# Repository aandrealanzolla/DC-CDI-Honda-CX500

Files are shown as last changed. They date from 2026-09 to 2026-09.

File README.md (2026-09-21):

# CX500 CDI — Custom ignition control unit

STM32-based custom DC-CDI for a Honda CX500, V-twin wasted-spark with variable reluctance pickups. Ignition timing with variable, custom advance curve and reactive/predictive logic.

## Project status

- **Rev 1.3** — Selected MCU: STM32F411CEU6. Wrong SMPS transformer dimensioning. Wrong pickup input signal conditioning circuit.
- **Rev 1.3.1** — Added a daughter board with MAX9927 IC for VR pickup reading. Replaced old step-up transformers with DA2034. Almost fully working and road-tested.
- **Rev 2.0** — SUPERSEDED. Improved routing, transformer footprint update, added JAE 18-pin automotive connector.
- **Rev 2.1** — SUPERSEDED. SMPS controller change: from LT3758 (Analog Devices) to LM3481 (TI). Transformer change: from Coilcraft DA2034 to Würth 750032052.
- **Rev 2.2** — IN PRODUCTION. Migration to STM32F410CBU6 for PCBA cost reduction (pin remapping required). SMPS voltage increased from 290V to 400V. CDI capacitance decreased from 2.2uF to 1.5uF. 

⚠️ **Use**: hobby project, intended for vintage or racing motorcycles. No EMC or road-use certification. See `docs/` for the regulatory considerations evaluated.

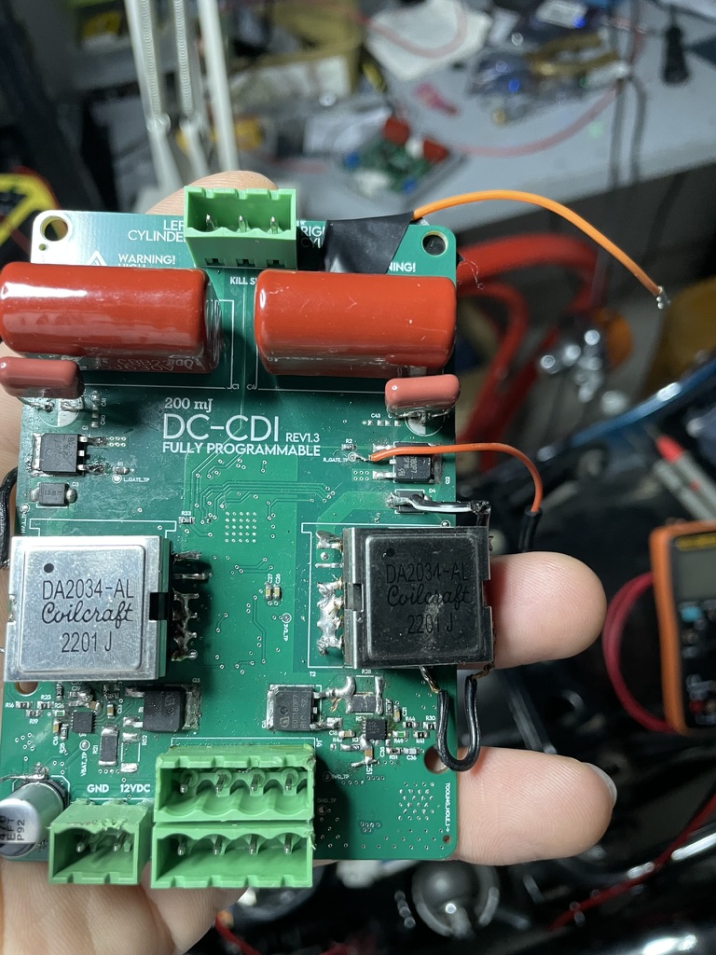
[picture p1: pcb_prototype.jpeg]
rev1.3 pcb assembled

rev1.3 pcb mounted
## Hardware architecture

### Rev 1.x (STM32F411CEU6)

| | Left channel | Right channel |
|---|---|---|
| Pickup capture | TIM3 CH3 | TIM2 CH3 |
| Spark coil output | TIM2 CH1 | TIM1 CH1 |

### Rev 2.x (STM32F410CBU6)

STM32F410 lacks TIM2/TIM3/TIM4 (value-line part), timers remapped as follows. TIM1 now
carries both right-channel output and left-channel capture on independent channels of the
same instance (shared prescaler/tick rate); TIM5 (32-bit) takes over TIM2's former dual role
(left output + right capture).

| | Left channel | Right channel |
|---|---|---|
| Pickup capture | TIM1 CH4 | TIM5 CH3 |
| Spark coil output | TIM5 CH1 | TIM1 CH1 |

Turned to Texas Instrument LM3481 SMPS controllers, to reduce complexity and costs. Increased capacitor charging voltage to 400V while reducing capacitance to 1.5uF to gain spark power (from 90mJ to 120mJ). 
Replaced ADP3654 with two 1EDN7511B.
Added external connector: JAE MX23A18 (waterproof) with UART access for engine map download/upload.

### Common to all revisions

- Pickup: MAX9927 (variable reluctance comparator), fixed angle 15° BTDC
- Power stage: IPD60R180P7 MOSFET (DPAK)
- External pins for kill switch, I2C sensors and analog sensor read with 5VDC power supply. 
- FW/Debug connector: STDC14 header (debug + calibration from the same node)

## Firmware architecture

- 4-branch state machine per channel: **reactive** (below 1500rpm, fixed 15° advance), **predictive-continuous**, **transition** (first threshold crossing), **drop-out**
- RPM projection: pure linear extrapolation, activation threshold `RPM_PROJECTION_MIN_RATE_PCT`
- Anti-stuck safety net: `PENDING_STUCK_TIMEOUT_MS`
- Advance map calibration: dedicated flash sector (last available sector), loaded at boot with fallback to safe defaults, writable over UART without reflashing (see `tools/cdi_calibration_tool.py`)
- UART telemetry at 115200 baud: rpm, advance, active branch, diagnostic counters (arm count, rejects, transitions, stuck-recovered)

## Repository structure

```
Progetto/
  DC_CDI_Honda_CX500_rev1.3/         - Altium project, rev 1.3 (working - with some rework, road-tested)
  DC_CDI_Honda_CX500_rev2.0/         - Altium project, rev 2.0 (SUPERSEDED)
  DC_CDI_Honda_CX500_rev2.1/         - Altium project, rev 2.1 (SUPERSEDED)
  DC_CDI_Honda_CX500_rev2.2/         - Altium project, rev 2.2 (IN PRODUCTION)
  DC_CDI_Honda_CX500_daughter_board_1/ - MAX9927 pickup daughter board
  Housing/
    rev1.3/                          - STEP/STL/OBJ enclosure models
    rev2.0/
  Documentazione/                    - PDFs
  simulazioni_LTspice/               - LTSpice simulation files
  firmware/                          - firmware version notes
  oldes_versions/                    - pre-rev1.3 Altium history
  smps_dimensionamento.xlsx
  stm32f411xx_RegisterMap.pdf
Video-Foto/                          - photos/videos of the build
Log_fw/                              - firmware telemetry logs
Misure/                              - oscilloscope captures
Sim/                                 - misc simulation files

```

## Main milestones (timeline)

1. Diagnosed and fixed cranking resets (gate resistor 0Ω → 10Ω, EMI from excessive dV/dt)
2. Replaced power stage: SCR → MOSFET
3. Fixed logic bugs: unstable RPM projection, drop-out arming a duplicate shot, queue firing on an expired target
4. Tuned advance map (aligned to stock AC-CDI reference, 37° at 5800rpm)
5. Isolated coupled noise on the left channel (daughter board repositioning)
6. Recurring MOSFET failures on the left channel — investigation ongoing (suspects: gate solder joint, driver, undersized Rds(on) on replacement parts)
7. Flash-based calibration system + PC tool
8. Migration to STM32F410 for cost reduction (rev 2.2)

## License

_TBD_

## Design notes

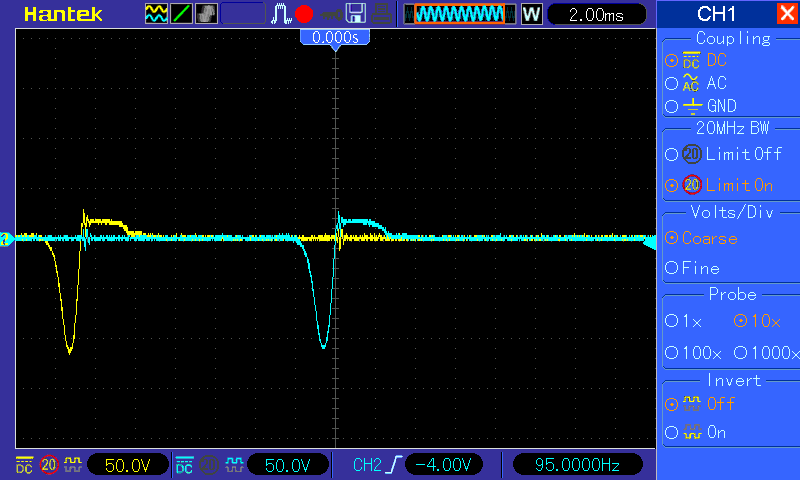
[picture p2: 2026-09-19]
Misure/pic_213_1.bmp

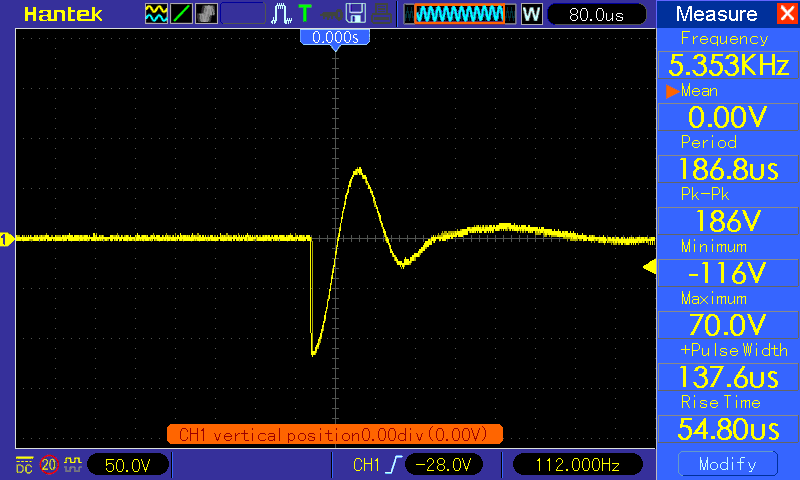
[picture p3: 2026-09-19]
Misure/pic_213_6.bmp

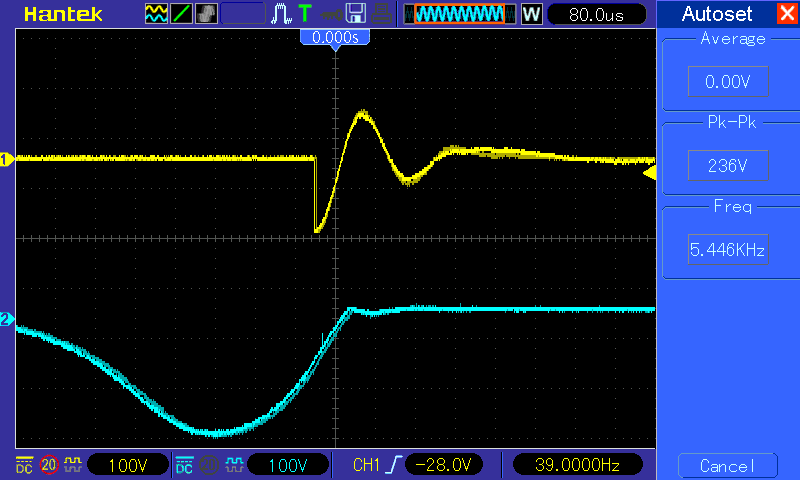
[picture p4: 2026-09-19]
Misure/pic_213_5.bmp

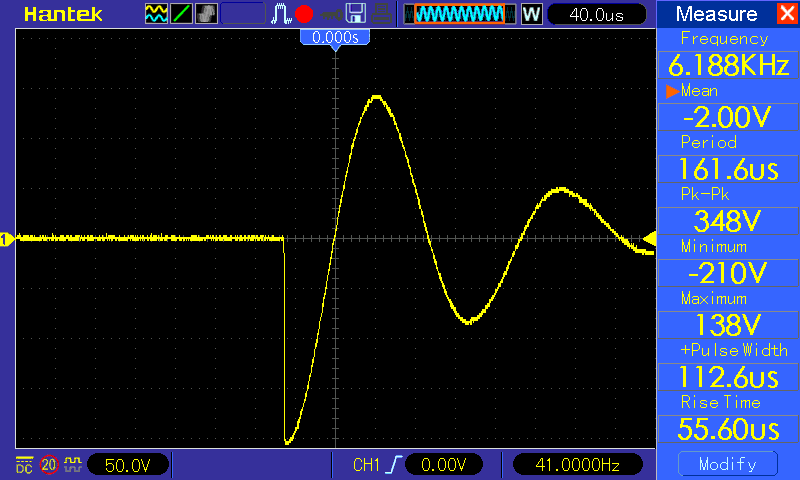
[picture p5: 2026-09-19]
Misure/pic_213_4.bmp

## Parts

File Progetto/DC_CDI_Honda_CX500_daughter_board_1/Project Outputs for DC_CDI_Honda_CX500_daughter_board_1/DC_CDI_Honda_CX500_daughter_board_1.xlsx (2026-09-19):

Name | Designator | Footprint | Value
Capacitor_0603 | C1 | 0603_FP | 47 nF
Capacitor_0603 | C2 | 0603_FP | 47 nF
Capacitor_0603 | C3 | 0603_FP | 100 nF
Resistor_0603 | R1 | 0603_FP | 10 kΩ
Resistor_0402 | R2 | 0402_fp | 10 kΩ
Resistor_0402 | R3 | 0402_fp | 100 Ω
Resistor_0402 | R4 | 0402_fp | 10 kΩ
Resistor_0603 | R5 | 0603_FP | 10 kΩ
Resistor_0402 | R6 | 0402_fp | 100 Ω
Resistor_0402 | R7 | 0402_fp | 100 Ω
MAX9926UAEE+ | U1 | FP-E16-1-MFG

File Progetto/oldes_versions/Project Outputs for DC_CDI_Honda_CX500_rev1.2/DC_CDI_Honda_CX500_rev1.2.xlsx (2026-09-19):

Comment | Designator | Footprint
GRM21BR61C475KA88L | C1 | CAPC2013X135X45LL10T25
BFC233820225 | C2 | FP-BFC233820225-MFG
B32672Z4105K000 | C3 | FP-B32672Z4105K000-MFG
C1608X5R1H105K080AB | C4 | FP-C1608-080-0_1-IPC_B
06035C104KAT4A | C5 | CAPC1608X90X35LL15T15
CC0603KRX7R9BB101 | C6 | FP-CC0603-DA-MFG
C0603C475K8PACTU | C7 | CAPC1608X87X35NL15T15
06035C103KAT2A | C8 | FP-0603-L_1_6_0_15-W_0_81-MFG
GRM21BR61C475KA88L | C9 | CAPC2013X135X45LL10T25
BFC233820225 | C10 | FP-BFC233820225-MFG
B32672Z4105K000 | C11 | FP-B32672Z4105K000-MFG
UUD1A102MNL1GS | C12 | NIC-CAPA2-10X10_V
C1608X5R1H105K080AB | C13 | FP-C1608-080-0_1-IPC_B
UUD1A102MNL1GS | C14 | NIC-CAPA2-10X10_V
CC0603KRX7R9BB101 | C15 | FP-CC0603-DA-MFG
06035C103KAT2A | C16 | FP-0603-L_1_6_0_15-W_0_81-MFG
GRM1555C1H102JA01D | C17 | FP-GRM155-0_05-IPC_B
GRM155R61A334KE15D | C18 | CAPC1005X55X25ML05T10
GRM155R61A334KE15D | C19 | CAPC1005X55X25ML05T10
GRM1555C1H331JA01D | C20 | FP-GRM155-0_05-MFG
GRM1555C1H102JA01D | C21 | FP-GRM155-0_05-IPC_B
GRM155R61A334KE15D | C22 | CAPC1005X55X25ML05T10
GRM155R61A334KE15D | C23 | CAPC1005X55X25ML05T10
GRM1555C1H331JA01D | C24 | FP-GRM155-0_05-MFG
CL05A106MP5NUNC | C25 | FP-CL05A106MP5NUNC-MFG
C0402C104K8PACTU | C26 | FP-C0402-BB-MFG
CL05A106MP5NUNC | C27 | FP-CL05A106MP5NUNC-MFG
C0402C104K8PACTU | C28 | FP-C0402-BB-MFG
CL05A106MP5NUNC | C29 | FP-CL05A106MP5NUNC-MFG
C0402C104K8PACTU | C30 | FP-C0402-BB-MFG
CL05A106MP5NUNC | C31 | FP-CL05A106MP5NUNC-MFG
C0402C104K8PACTU | C32 | FP-C0402-BB-MFG
GRM155R61A225KE95D | C33 | FP-GRM155-0_05-MFG
GRM155R61A225KE95D | C34 | FP-GRM155-0_05-MFG
C0402C104K8PACTU | C35 | FP-C0402-BB-MFG
C0402C104K8PACTU | C36 | FP-C0402-BB-MFG
C0402C104K8PACTU | C37 | FP-C0402-BB-MFG
C3D03060E | D1 | FP-TO-252-2_v2-MFG
C3D03060E | D2 | FP-TO-252-2_v2-MFG
150080SS75000 | D3 | WL-SMCW_0805_150080xx75000
150080SS75000 | D4 | WL-SMCW_0805_150080xx75000
FTSH-107-01-L-DV-K | J1 | FP-FTSH-107-01-L-DV-K-MFG
53047-0410 | J2 | FP-53047-0410-MFG
691701510002B | P1 | 691701510002B
691701510002B | P2 | 691701510002B
691701510002B | P3 | 691701510002B
691701510002B | P4 | 691701510002B
IPD600N25N3 | Q1 | INF-PG-TO252-3-11_A_L
IPD600N25N3 | Q2 | FP-PG-TO252-3-MFG
IPD600N25N3 | Q3 | INF-PG-TO252-3-11_A_L
IPD600N25N3 | Q4 | FP-PG-TO252-3-MFG
IPD600N25N3 | Q5 | INF-PG-TO252-3-11_A_L
PMV56XN,215 | Q6 | NXP-SOT23_L
CRCW060347R0FKEA | R1 | RESC1609X50X30LL10T20
RC0603FR-07470KL | R2 | RESC1608X55X25ML10T15
ERJ-3EKF1243V | R3 | RESC1608X55X30LL15T15
RC0603FR-0756KL | R4 | RESC1608X55X25LL10T15
RC0603FR-071KL | R5 | FP-RC0603-0_55-IPC_C
CRA2512-FZ-R020ELF | R6 | FP-CRA2512-MFG
RC0603FR-07470KL | R7 | RESC1608X55X25ML10T15
RC0603FR-07120KL | R8 | RESC1608X55X25NL10T15
RC0603FR-0710KL | R9 | FP-RC0603-0_55-IPC_C
ERJ-3EKF1243V | R10 | RESC1608X55X30LL15T15
RC0603FR-0756KL | R11 | RESC1608X55X25LL10T15
RC0603FR-071KL | R12 | FP-RC0603-0_55-IPC_C
CRCW060347R0FKEA | R13 | RESC1609X50X30LL10T20
RC0603FR-07120KL | R14 | RESC1608X55X25NL10T15
CRA2512-FZ-R020ELF | R15 | FP-CRA2512-MFG
RC0603FR-0710KL | R16 | FP-RC0603-0_55-IPC_C
RC0402FR-07560KL | R17 | RESC1005X40X25LL05T10
RC0402FR-0722KL | R18 | RESC1005X40X25NL05T10
RC0402FR-0722KL | R19 | RESC1005X40X25NL05T10
RC0402FR-0722KL | R20 | RESC1005X40X25NL05T10
RC0402FR-072M2L | R21 | RESC1005X40X25ML05T10
RC0402FR-071M5L | R22 | RESC1005X40X25NL05T10
RC0402FR-07560KL | R23 | RESC1005X40X25LL05T10
RC0402FR-0722KL | R24 | RESC1005X40X25NL05T10
RC0402FR-0722KL | R25 | RESC1005X40X25NL05T10
RC0402FR-0722KL | R26 | RESC1005X40X25NL05T10
RC0402FR-072M2L | R27 | RESC1005X40X25ML05T10
RC0402FR-071M5L | R28 | RESC1005X40X25NL05T10
RC0402FR-0710KL | R29 | RESC1005X40X25LL05T10
RC0402FR-0710KL | R30 | RESC1005X40X25LL05T10
RC0402FR-0710KL | R31 | RESC1005X40X25LL05T10
RC0402FR-07510RL | R32 | RESC1005X40X25LL05T10
RC0402FR-07510RL | R33 | RESC1005X40X25LL05T10
RC0402FR-0710KL | R34 | RESC1005X40X25LL05T10
RC0402JR-070RL | R35 | RESC1005X40X25NL05T10
RC0402JR-070RL | R36 | RESC1005X40X25NL05T10
RC0402FR-0710KL | R37 | RESC1005X40X25LL05T10
RC0402JR-074K7L | R38 | FP-RC0402-0_4-MFG
RC0402JR-074K7L | R39 | FP-RC0402-0_4-MFG
RC0603FR-07470KL | R50 | RESC1608X55X25ML10T15
RC0603FR-07470KL | R51 | RESC1608X55X25ML10T15
74080 | T1 | 74080
74080 | T2 | 74080
LT3758EDD#PBF | U1 | FP-DD-10-05-08-1699-IPC_B
ADP3654ARHZ-RL | U2 | FP-RH-8-1-IPC_C
LT3758EDD#PBF | U3 | FP-DD-10-05-08-1699-IPC_B
AD8602DRM-REEL | U4 | ADI-RM-8_M
AD8602DRM-REEL | U5 | ADI-RM-8_M
AMS1117-3.3 | U7 | FP-AMS1117-IPC_C
STM32H750VBT6 | U8 | FP-LQFP100-1L-MFG
AD8031ARTZ-REEL7 | U9 | ADI-RJ-5_L

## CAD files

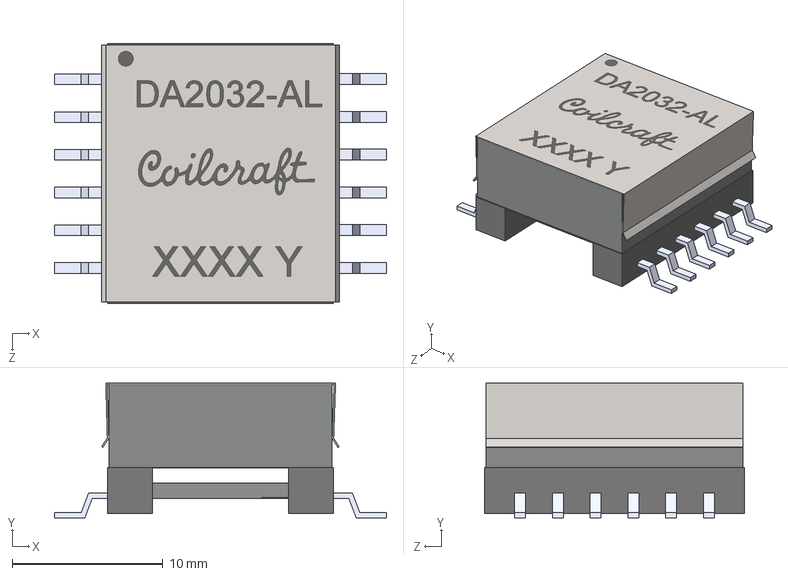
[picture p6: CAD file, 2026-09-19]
Progetto/DC_CDI_Honda_CX500_rev2.2/Coilcraft-DA2032-AL.STEP
22.0 x 8.94 x 17.2 mm

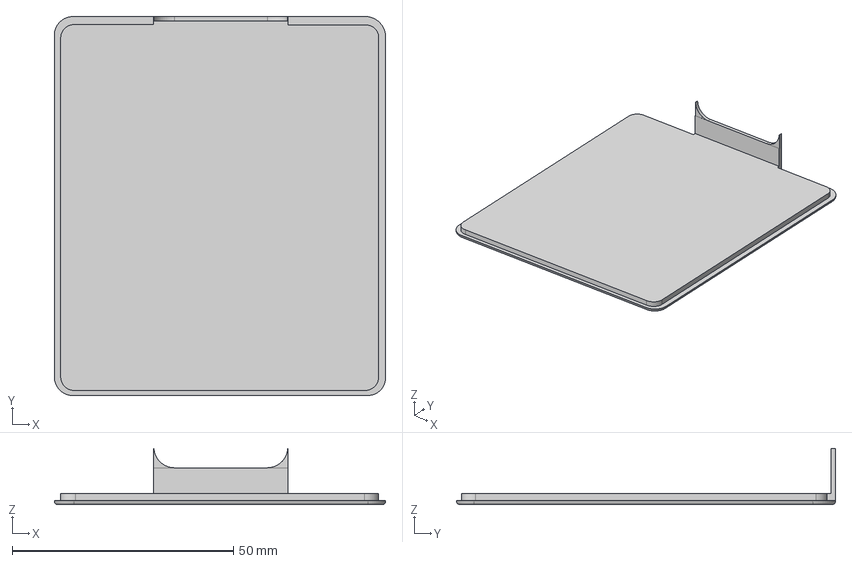
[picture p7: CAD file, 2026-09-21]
Progetto/Housing/rev2.2/housing_bot.step
74.9 x 85.7 x 12.7 mm

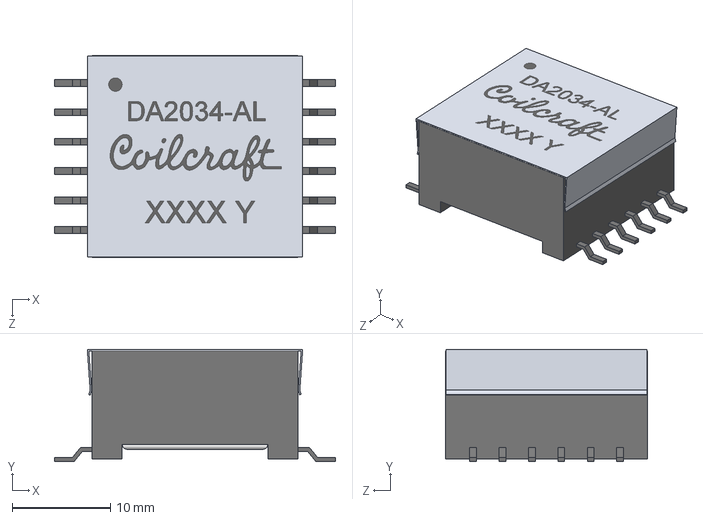
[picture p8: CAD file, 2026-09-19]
Progetto/DC_CDI_Honda_CX500_rev2.2/Coilcraft-DA2034-AL.STEP
28.6 x 11.4 x 20.6 mm

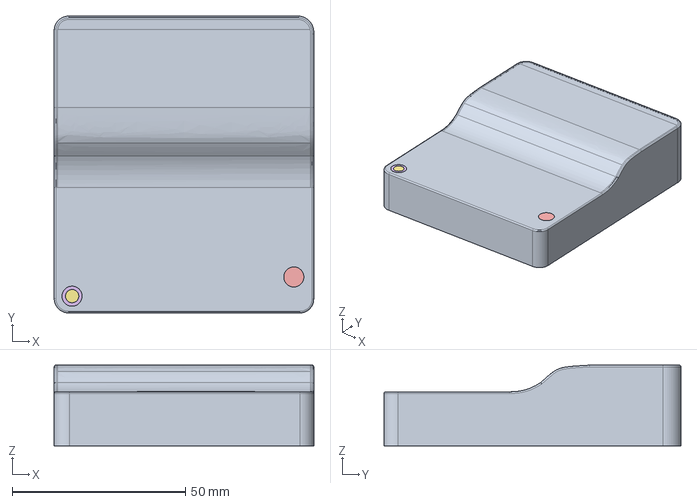
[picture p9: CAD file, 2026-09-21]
Progetto/Housing/rev2.2/housing_top.step
74.9 x 85.7 x 23.3 mm

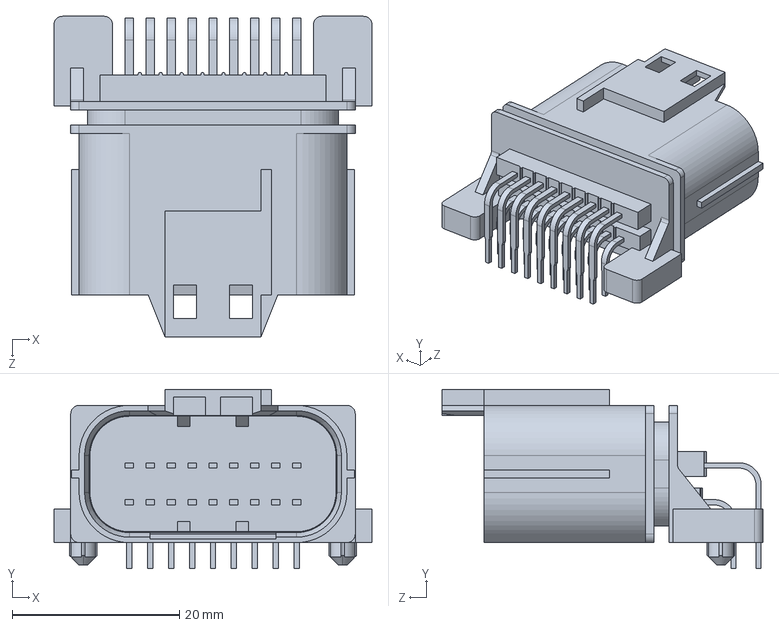
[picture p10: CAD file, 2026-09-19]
Progetto/DC_CDI_Honda_CX500_rev2.2/MX23A18NF1.stp
38.0 x 21.4 x 38.3 mm

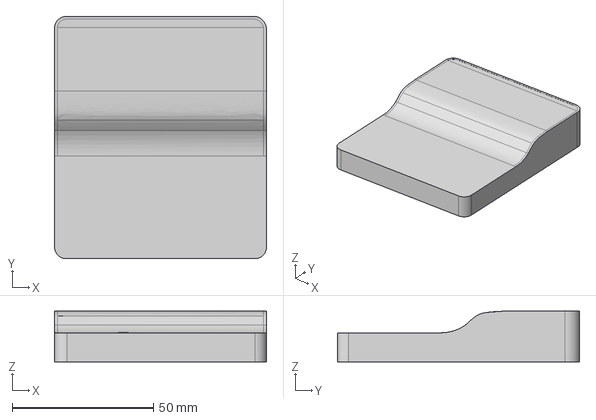
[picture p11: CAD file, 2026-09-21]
Progetto/Housing/rev2.2/housing.step
74.9 x 85.7 x 18.0 mm

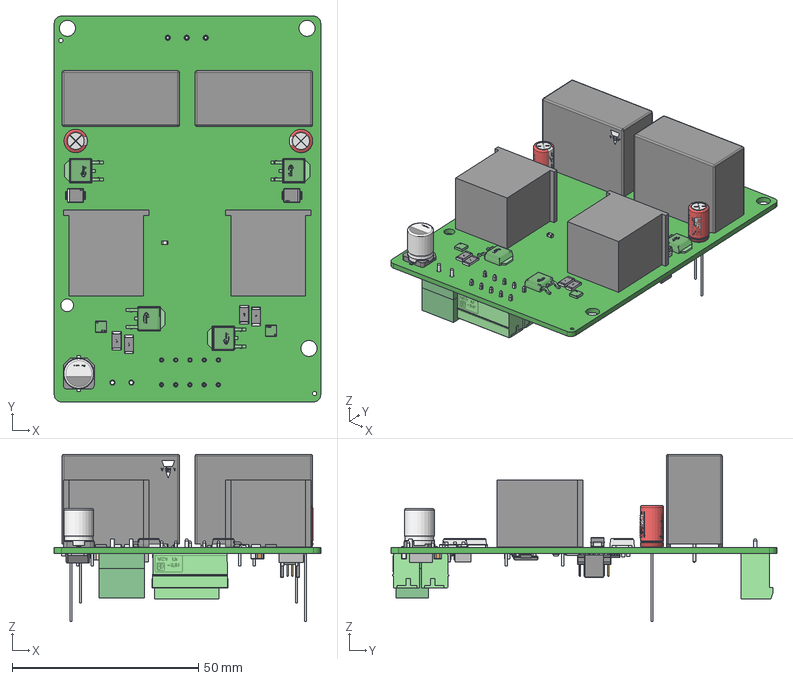
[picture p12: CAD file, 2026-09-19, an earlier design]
Progetto/Housing/rev1.3/dc_cdi_cx500_2.step
71.5 x 103.5 x 44.9 mm
Extruded x 24
Terminals x 8
Sub x 4
Coating x 4
Logo x 8
Leads x 2
side x 12
Yageo x 2
Panasonic
pins
top
part number
DPAK250P1030X230-3_PRSS0004ZG-A_N
MSTBVA 2,5_xx-G-5,08 green_3
Pin x 3
Notch 2
Analog Devices x 2
circle x 2
BODY_M08A_35
LEAD_M08A_57 x 8
MANIFOLD_SOLID_BREP_2784
MANIFOLD_SOLID_BREP_2935
MANIFOLD_SOLID_BREP_3086
MANIFOLD_SOLID_BREP_3237
Analog Devices Logo
Infineon x 4
FTSH-107-01-F-DV-K_body
FTSH-107-01-F-DV-K_pins1
FTSH-107-01-F-DV-K_pins2
Samtec
Pin1_Triangle
housing x 2
cover x 2
base_2 x 2
base x 2
marking x 2
Pins x 2
Marking x 2
Onsemi Updated Logo x 2
Murata x 4
6.3x11x2.5x0.5 x 4
Vishay logo x 2

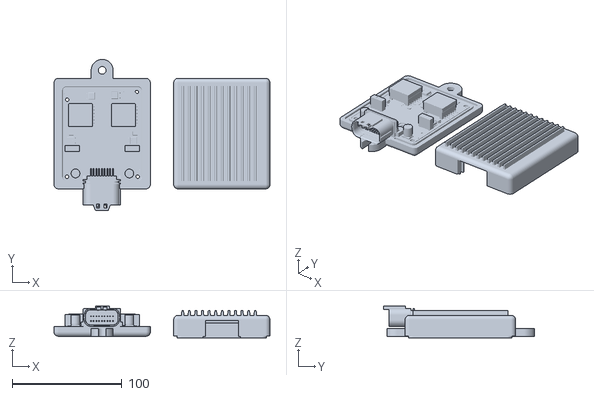
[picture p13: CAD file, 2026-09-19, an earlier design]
Progetto/Housing/rev2.0/dc_cdi_housing_000.stl
196.4 x 137.5 x 28.7

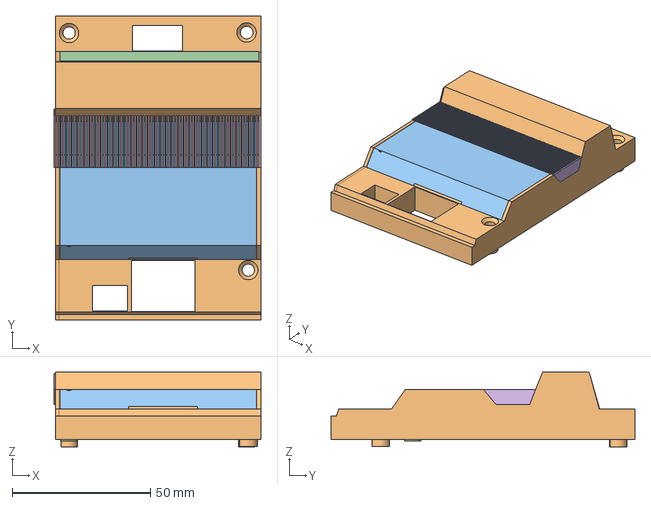
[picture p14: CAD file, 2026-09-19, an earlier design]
Progetto/Housing/rev1.3/dc_cdi_cx500_housing_top.step
74.7 x 110.0 x 27.1 mm

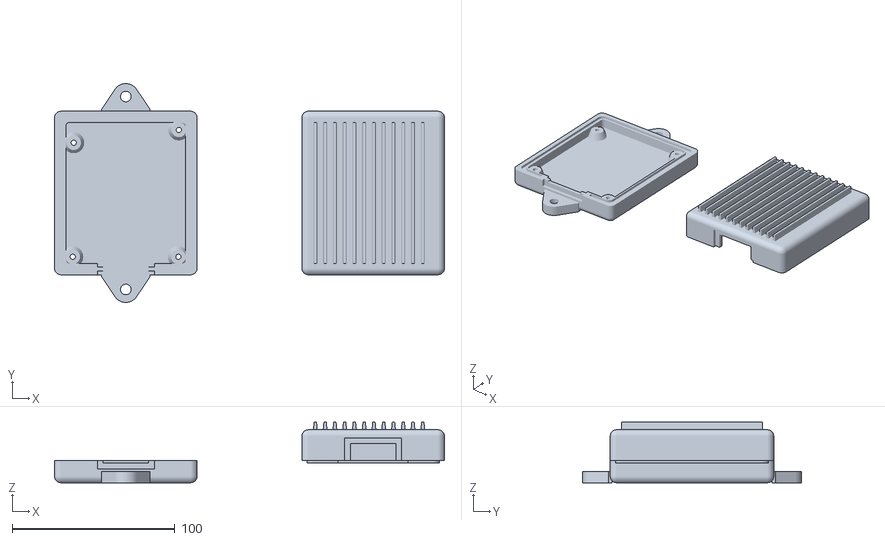
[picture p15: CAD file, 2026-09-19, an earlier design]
Progetto/Housing/rev2.0/dc_cdi_housing_002.stl
239.6 x 134.5 x 37.2

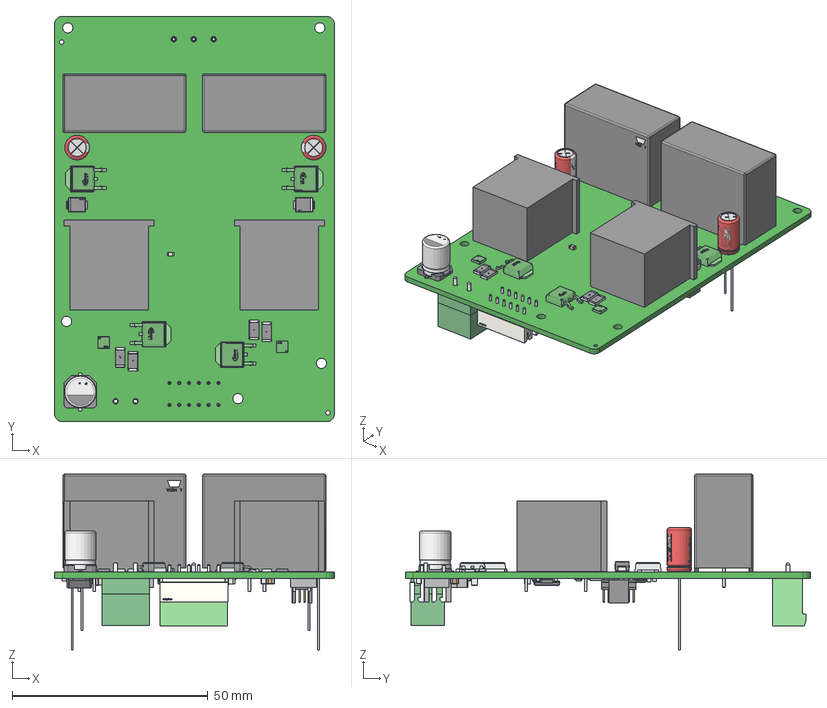
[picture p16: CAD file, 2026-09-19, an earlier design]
Progetto/Housing/rev1.3/dc_cdi_cx500.step
71.5 x 103.5 x 44.9 mm
Terminals x 8
Sub x 4
Coating x 4
Logo x 8
Molex x 2
Leads x 2
Extruded x 24
side x 12
Yageo x 2
Panasonic
pins
top
part number
DPAK250P1030X230-3_PRSS0004ZG-A_N
MSTBVA 2,5_xx-G-5,08 green_3
Pin x 3
Notch 2
Analog Devices x 2
circle x 2
BODY_M08A_35
LEAD_M08A_57 x 8
MANIFOLD_SOLID_BREP_2784
MANIFOLD_SOLID_BREP_2935
MANIFOLD_SOLID_BREP_3086
MANIFOLD_SOLID_BREP_3237
Analog Devices Logo
Infineon x 4
FTSH-107-01-F-DV-K_body
FTSH-107-01-F-DV-K_pins1
FTSH-107-01-F-DV-K_pins2
Samtec
Pin1_Triangle
housing x 2
cover x 2
base_2 x 2
base x 2
marking x 2
Pins x 2
Marking x 2
Onsemi Updated Logo x 2
Murata x 4
6.3x11x2.5x0.5 x 4
Vishay logo x 2

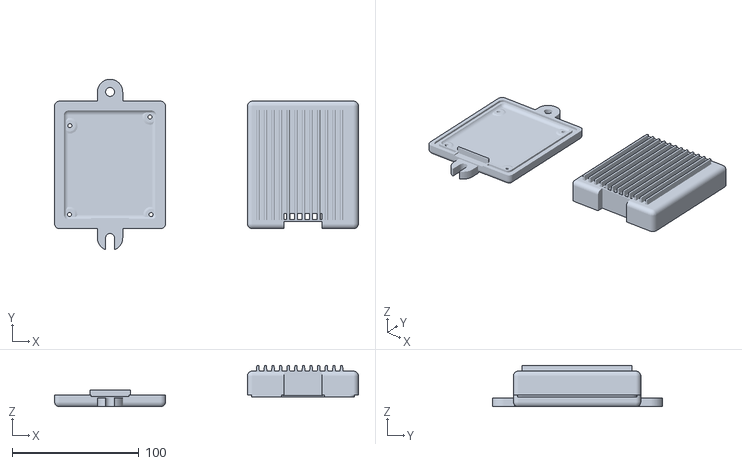
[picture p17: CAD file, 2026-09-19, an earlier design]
Progetto/Housing/rev2.0/dc_cdi_housing_004.stl
239.6 x 134.4 x 32.7

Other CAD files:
Progetto/Housing/rev2.0/dc_cdi_housing.scad
Progetto/Housing/rev1.3/dc_cdi_cx500_back.f3d
Progetto/Housing/rev1.3/dc_cdi_cx500_conn_housing.step
Progetto/Housing/rev1.3/dc_cdi_cx500_conn_housing.stl
Progetto/Housing/rev1.3/dc_cdi_cx500_conn_top_step.step
Progetto/Housing/rev1.3/dc_cdi_cx500_housing.obj
Progetto/Housing/rev1.3/dc_cdi_cx500_housing.stl
Progetto/Housing/rev1.3/dc_cdi_cx500_housing_bottom.step
Progetto/Housing/rev1.3/housing_cx500_ac_cdi_pcb_rev2.stl
Progetto/Housing/rev2.0/dc_cdi_housing_.obj
Progetto/Housing/rev2.0/dc_cdi_housing_001.stl
Progetto/Housing/rev2.0/dc_cdi_housing_003.stl
Progetto/Housing/rev2.0/dc_cdi_housing_005.stl
Progetto/Housing/rev2.0/dc_cdi_housing_def.stl
Progetto/Housing/rev2.0/dc_cdi_rev2.0.step

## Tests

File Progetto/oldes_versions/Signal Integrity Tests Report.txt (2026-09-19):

Falling Edge Overshoot

The following nets have values outside defined tolerance levels :

Falling Edge Undershoot

The following nets have values outside defined tolerance levels :

Rising Edge Overshoot

The following nets have values outside defined tolerance levels :

Rising Edge Undershoot

The following nets have values outside defined tolerance levels :

The following nets were not able to be analysed :

NetR37_2
NetR36_2
NetR35_2
NetD4_2
NetR33_2
NetD3_2
NetR32_2
NetR14_2
NetR8_2
NetC2_1
NetR3_1
NetQ2_1
NetR1_1
NetQ3_3
NetQ3_1
NetQ3_2
NetQ1_3
NetQ1_1
NetQ1_2
NetJ1_14
NetJ1_13
NetJ1_12
NetJ1_11
NetJ1_6
NetJ1_4
NetD1_2
NetC34_1
NetC33_1
NetC22_2
NetC13_2
NetC10_1
NetC10_2
NetD2_2
NetQ4_1
NetR10_1
NetR13_2
NetC4_2
NetC2_2

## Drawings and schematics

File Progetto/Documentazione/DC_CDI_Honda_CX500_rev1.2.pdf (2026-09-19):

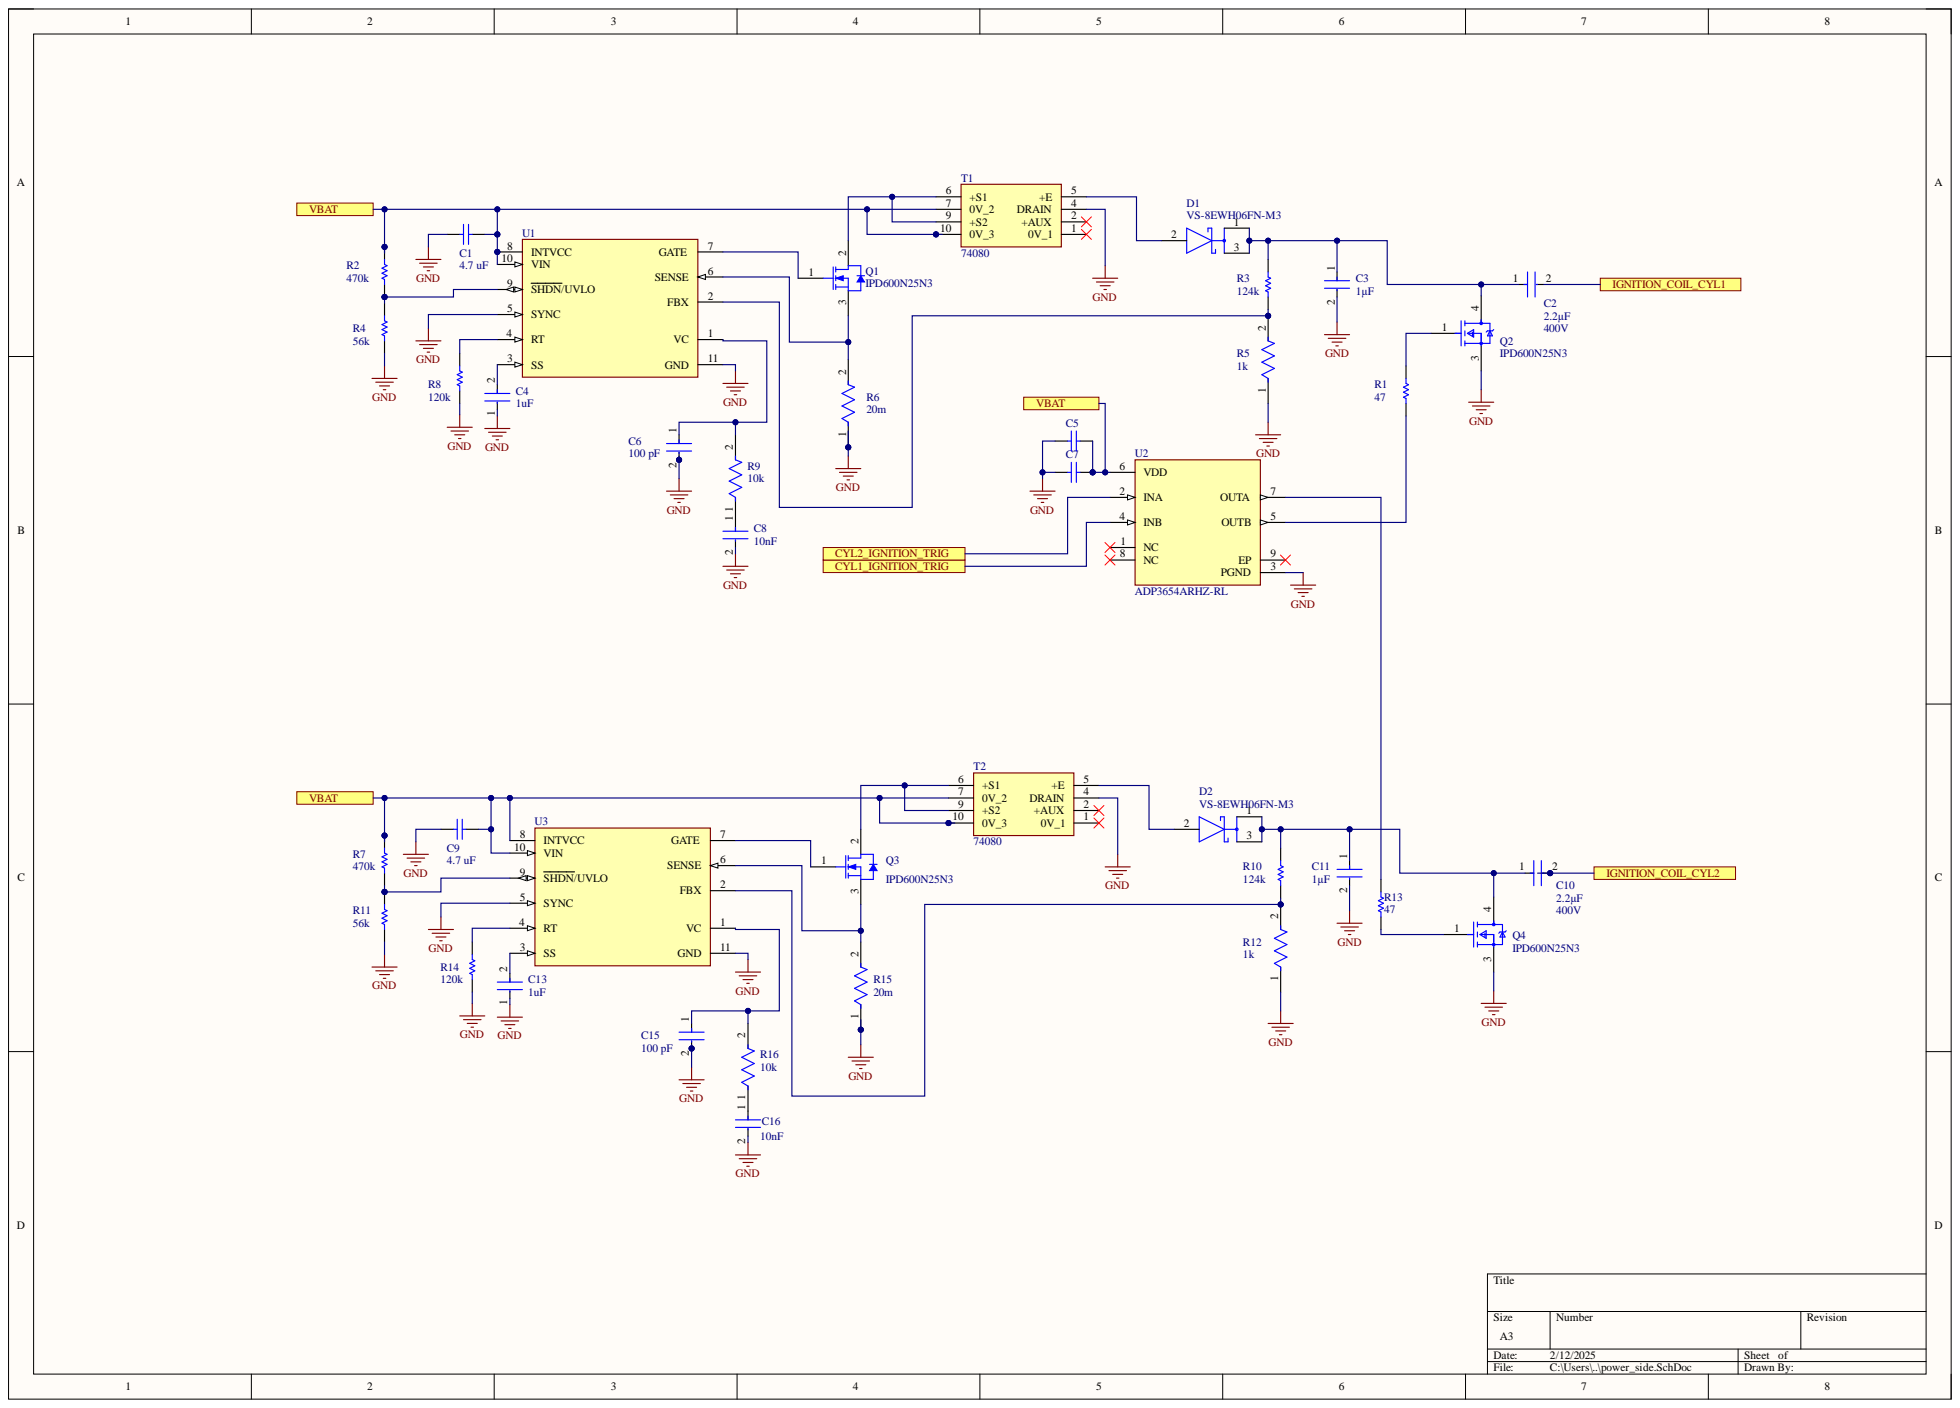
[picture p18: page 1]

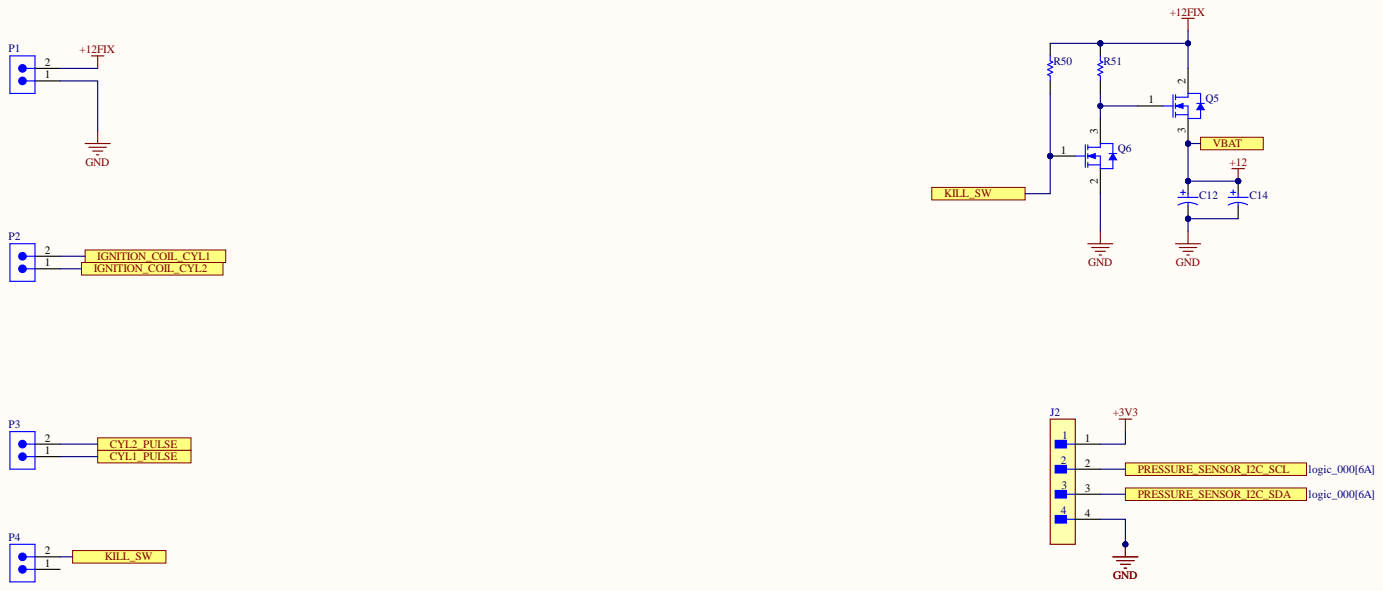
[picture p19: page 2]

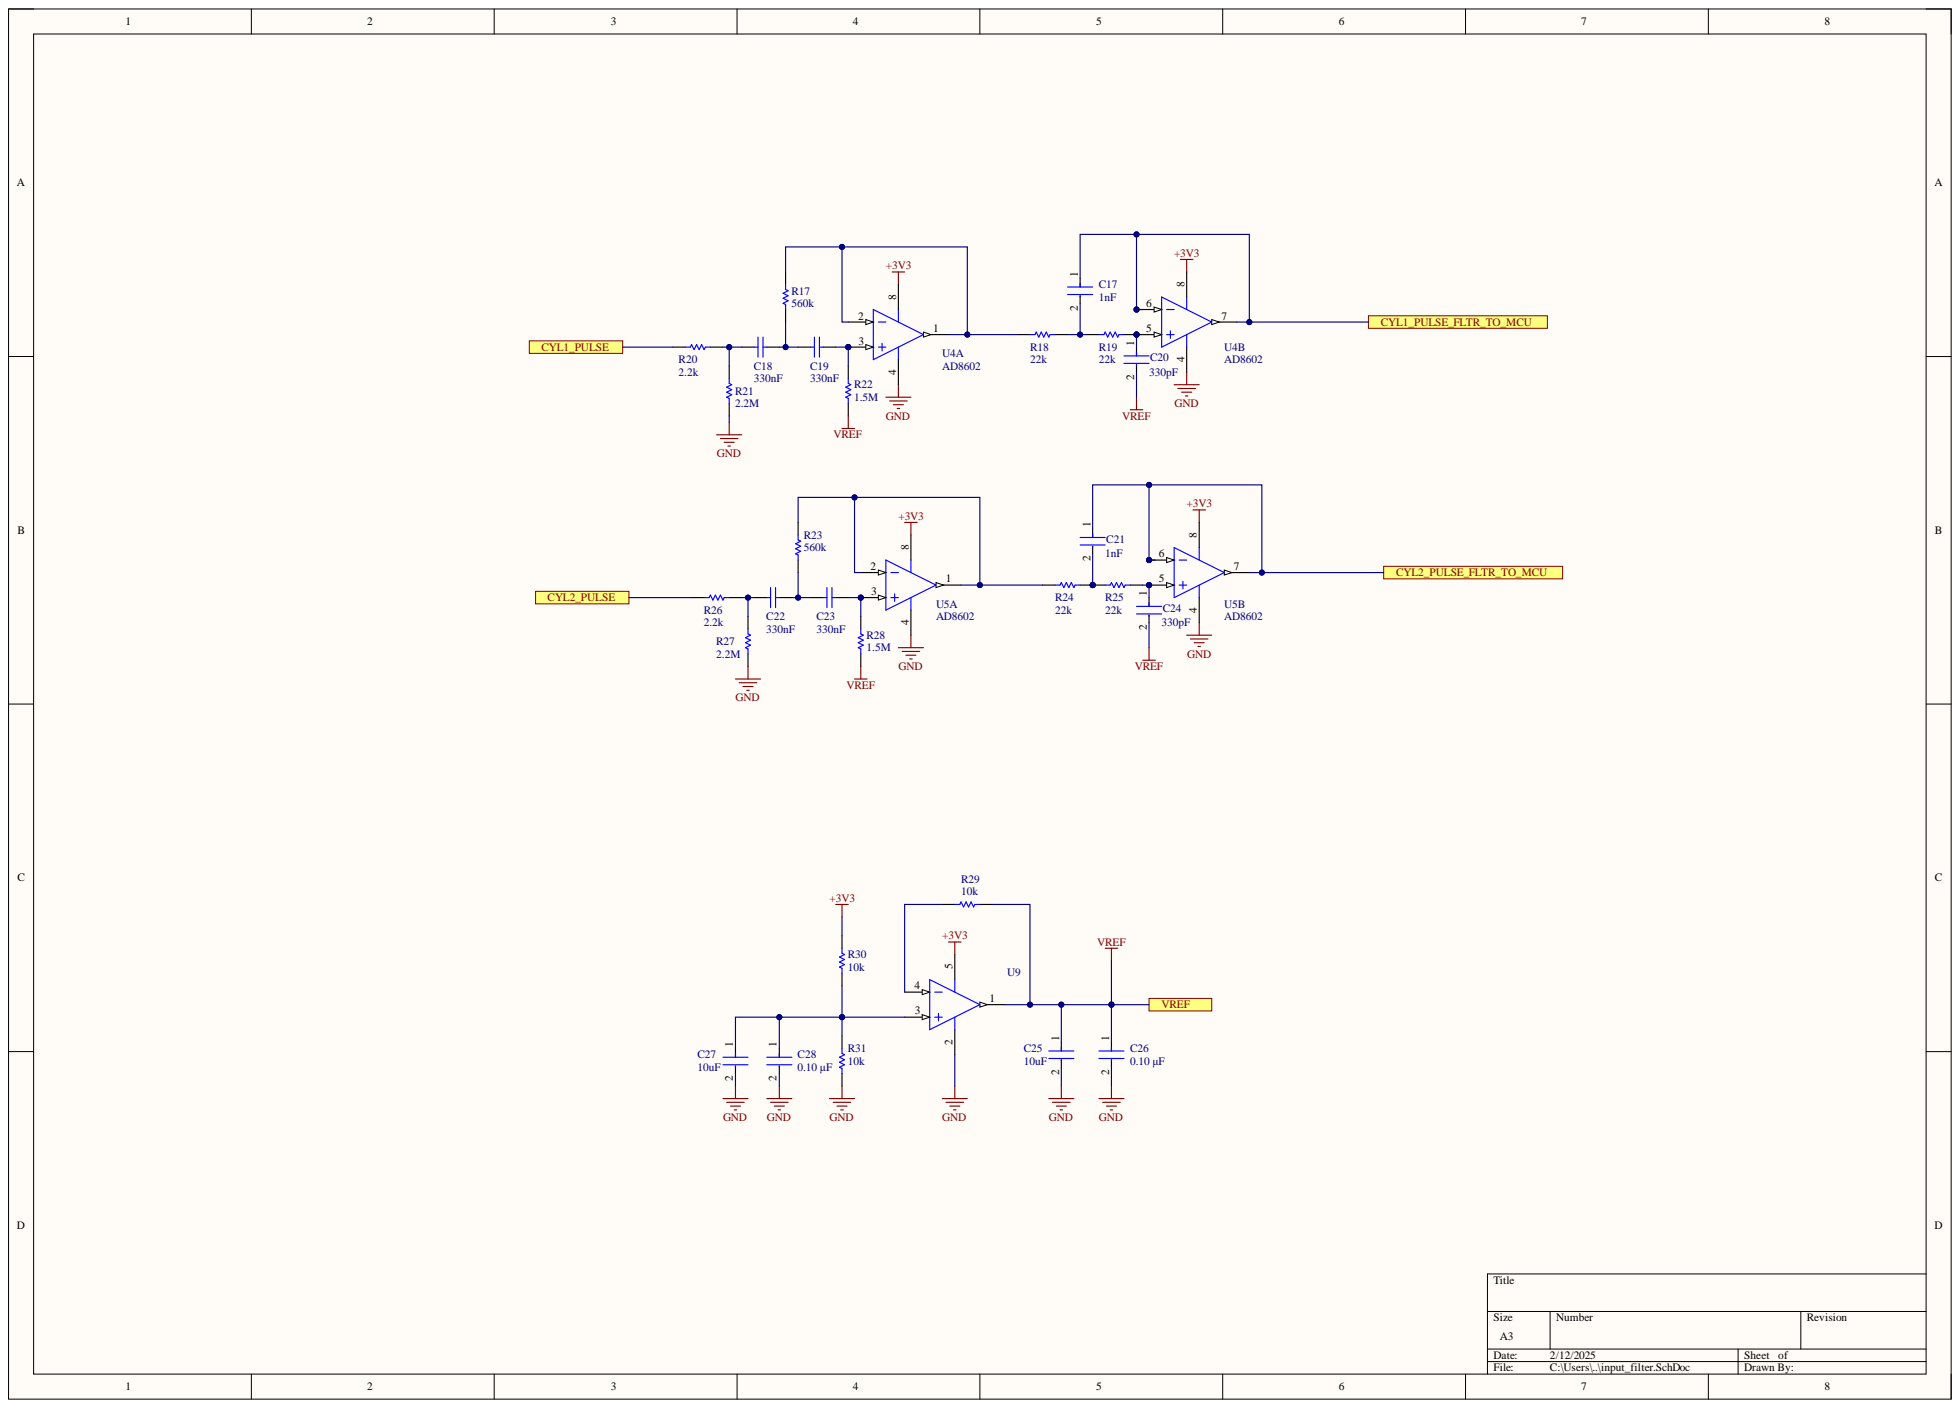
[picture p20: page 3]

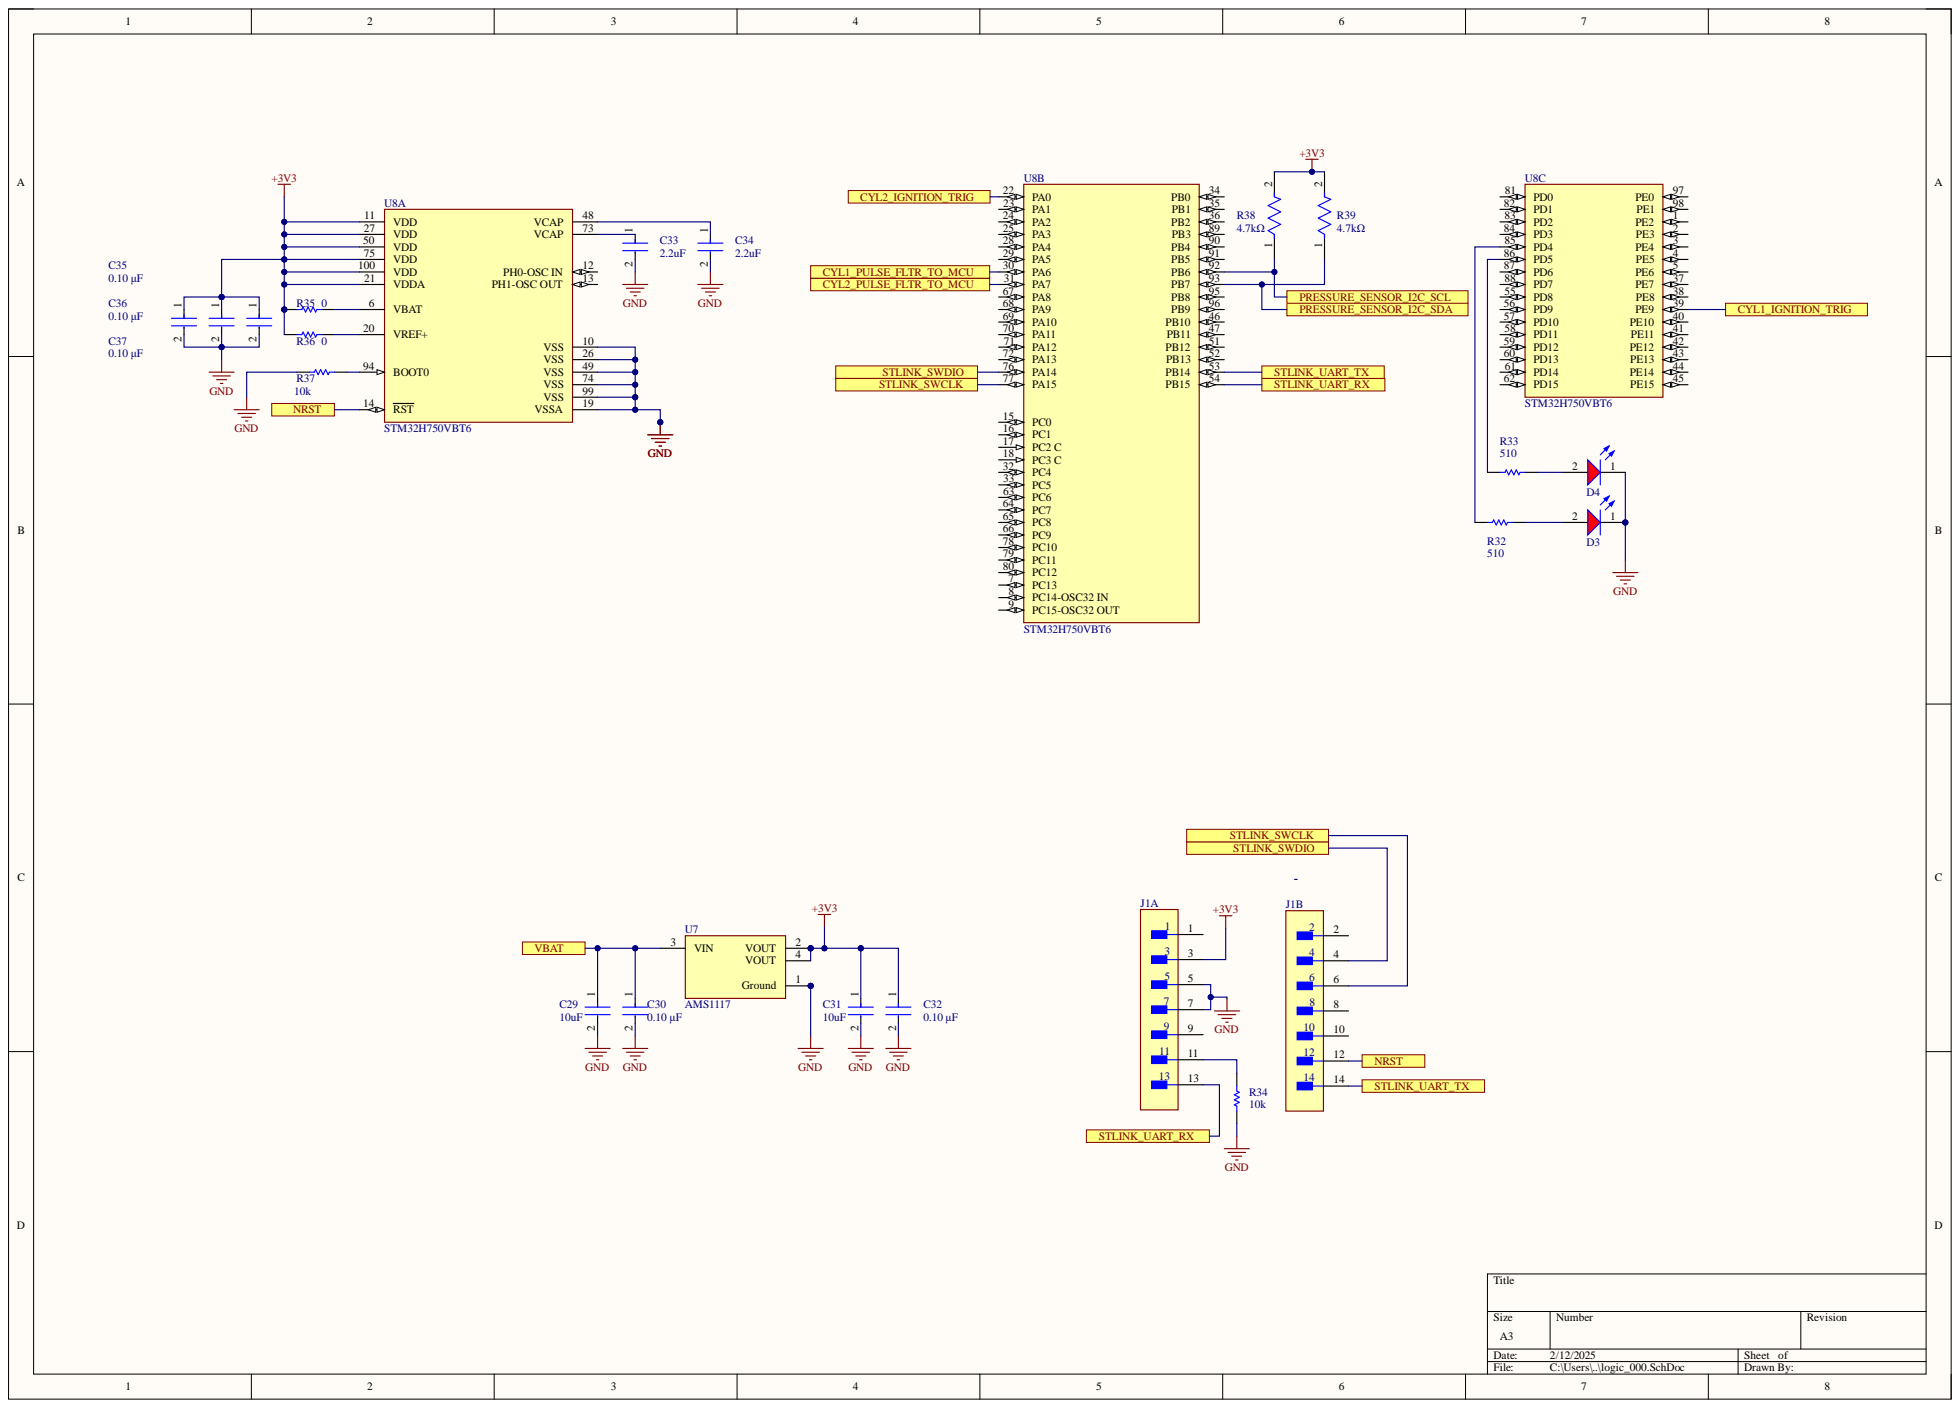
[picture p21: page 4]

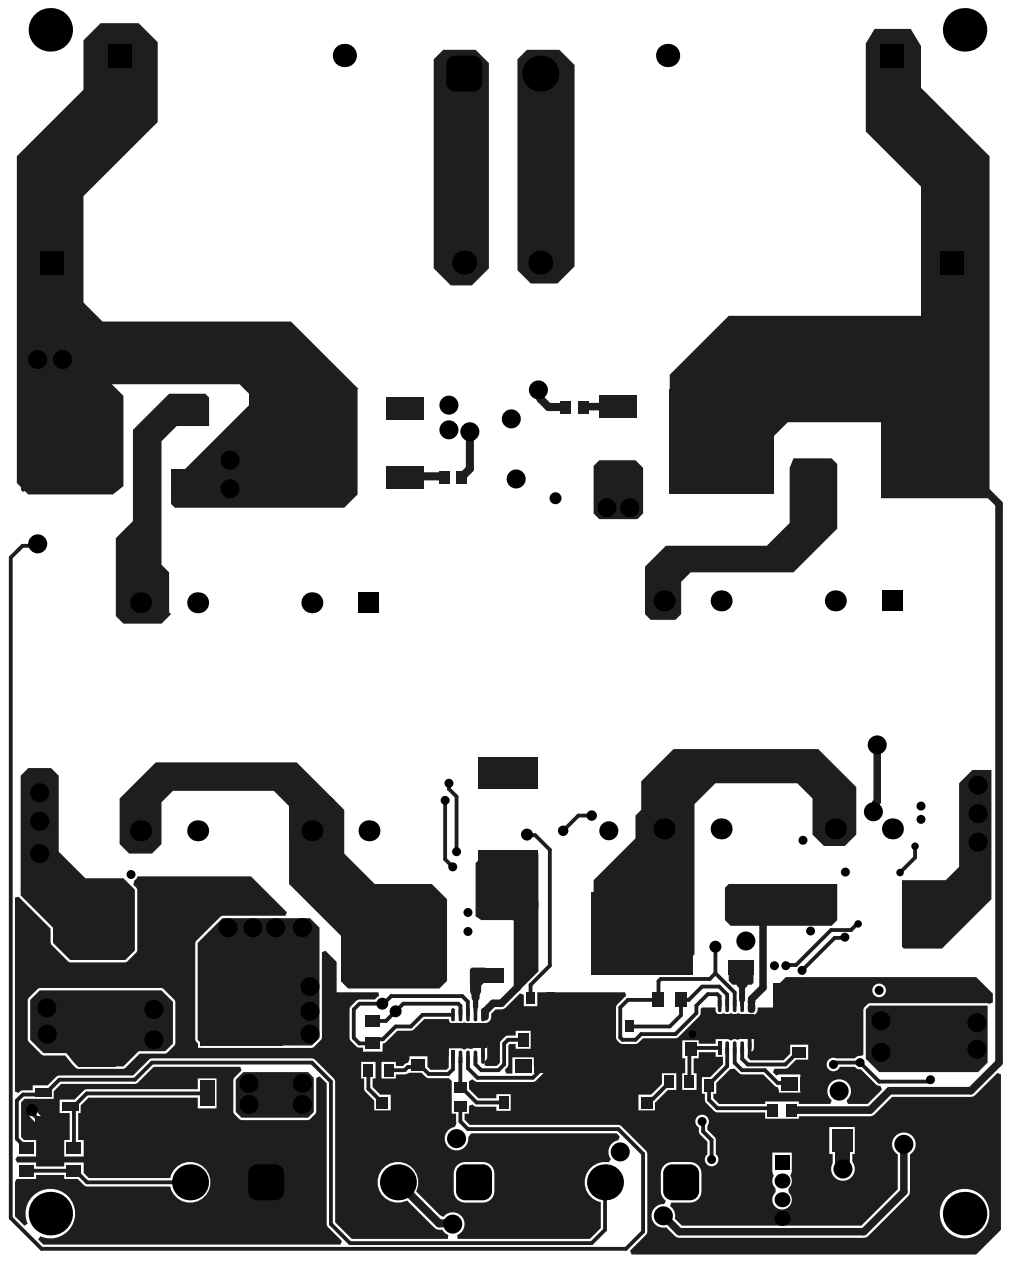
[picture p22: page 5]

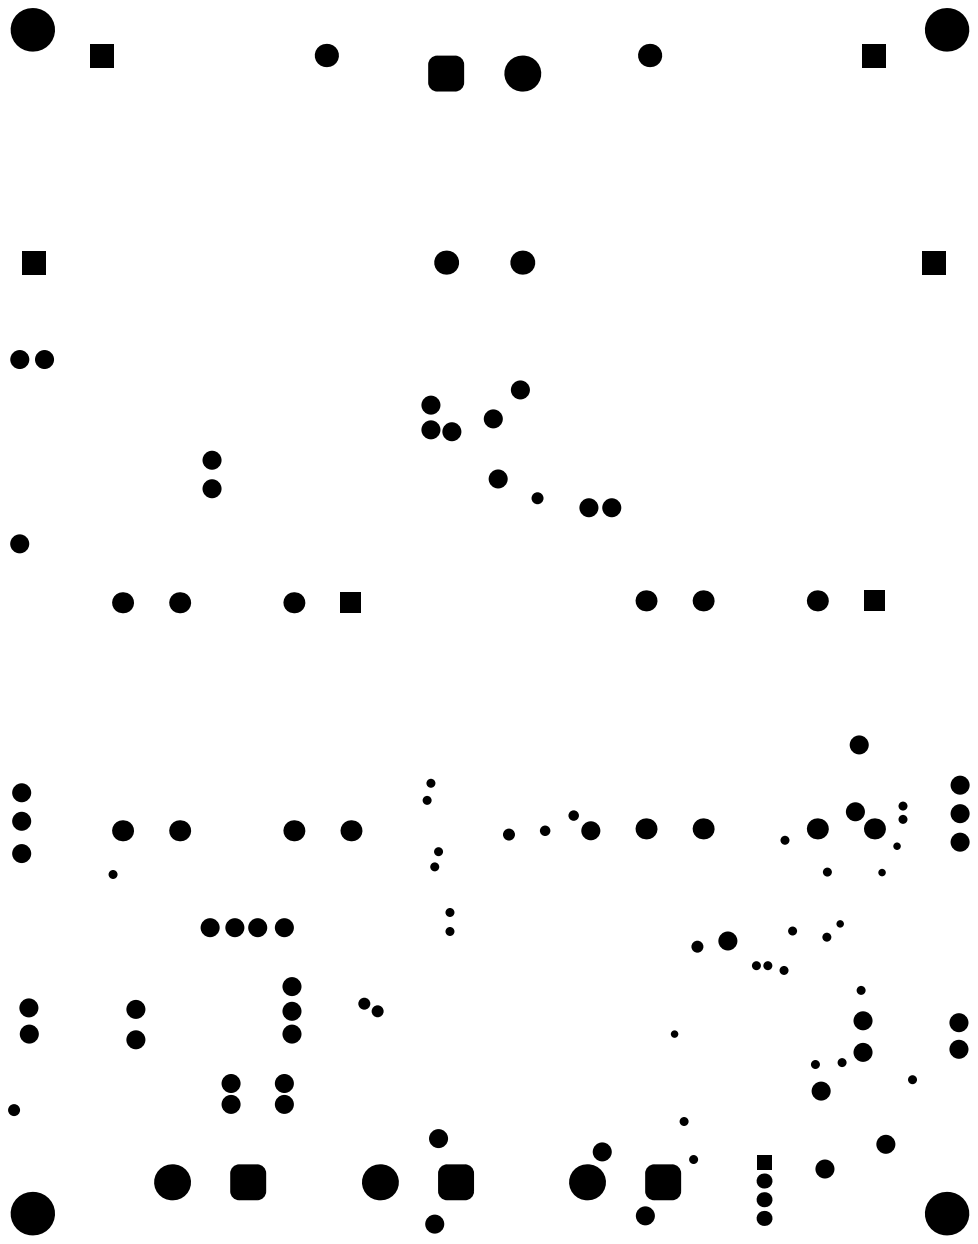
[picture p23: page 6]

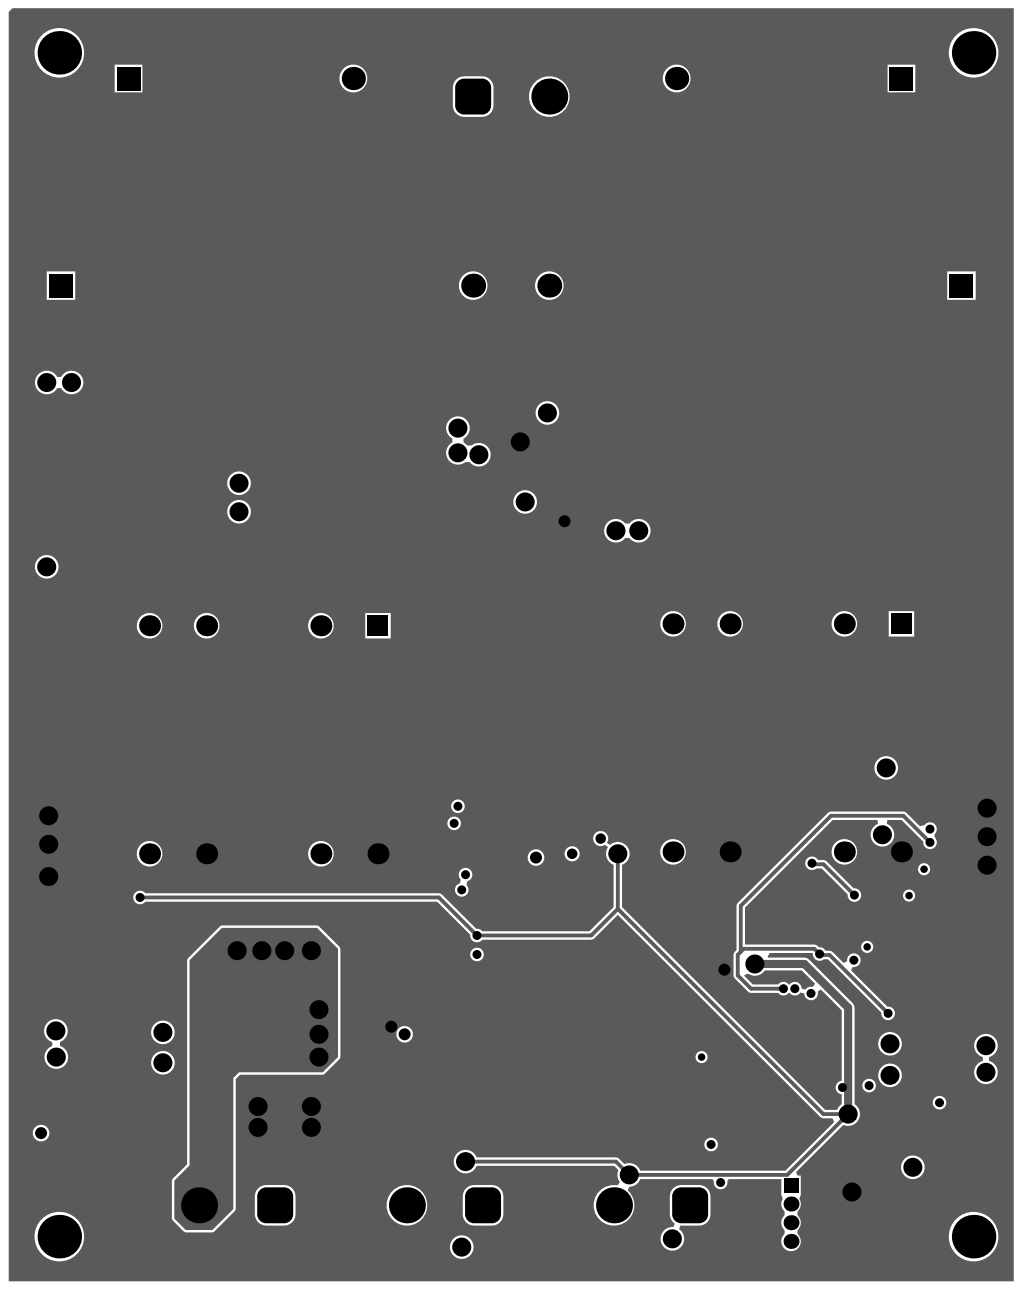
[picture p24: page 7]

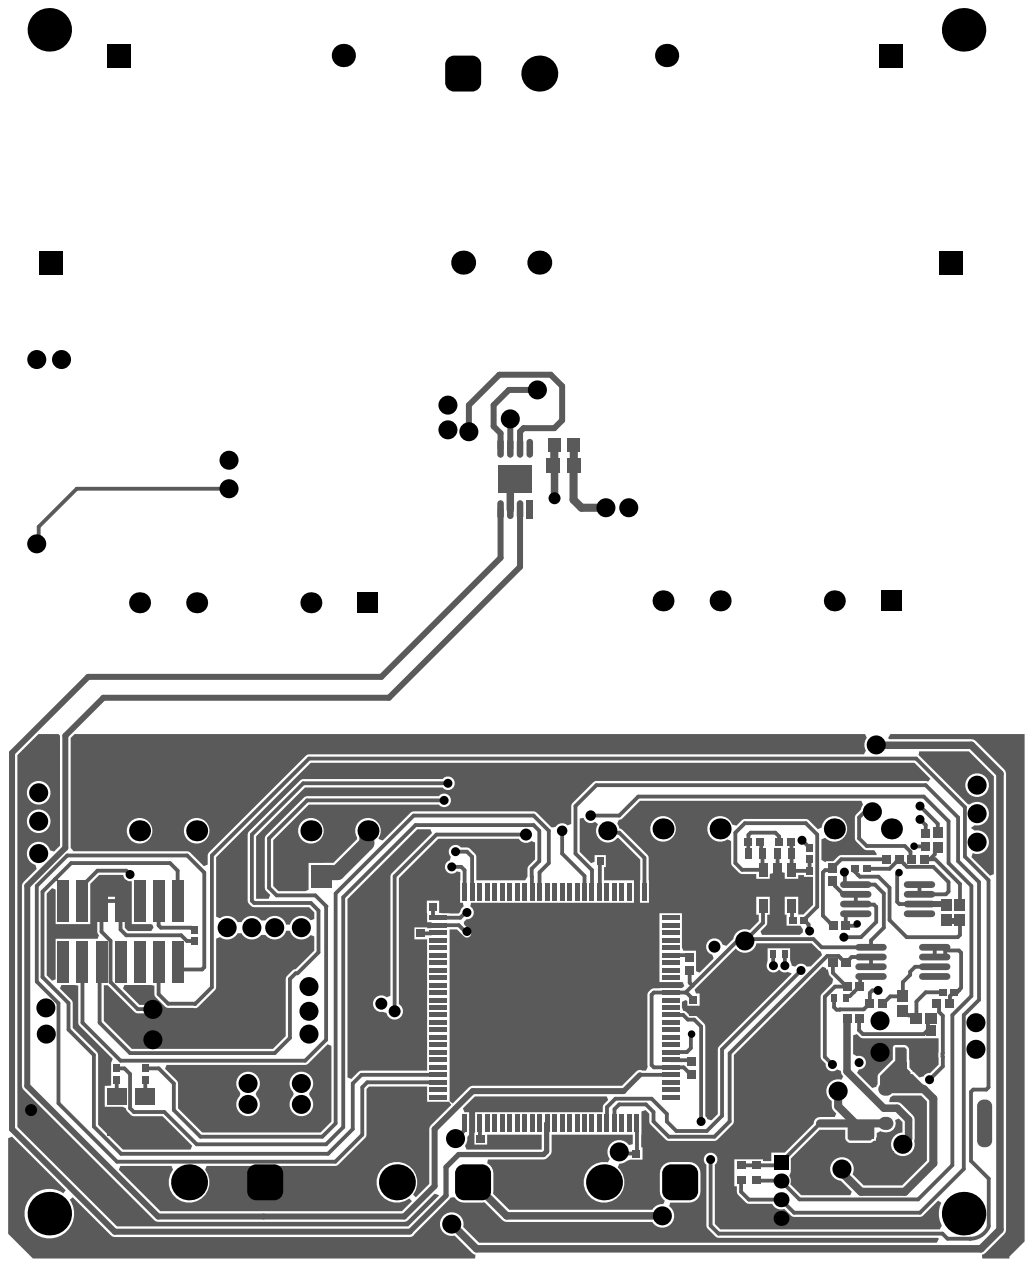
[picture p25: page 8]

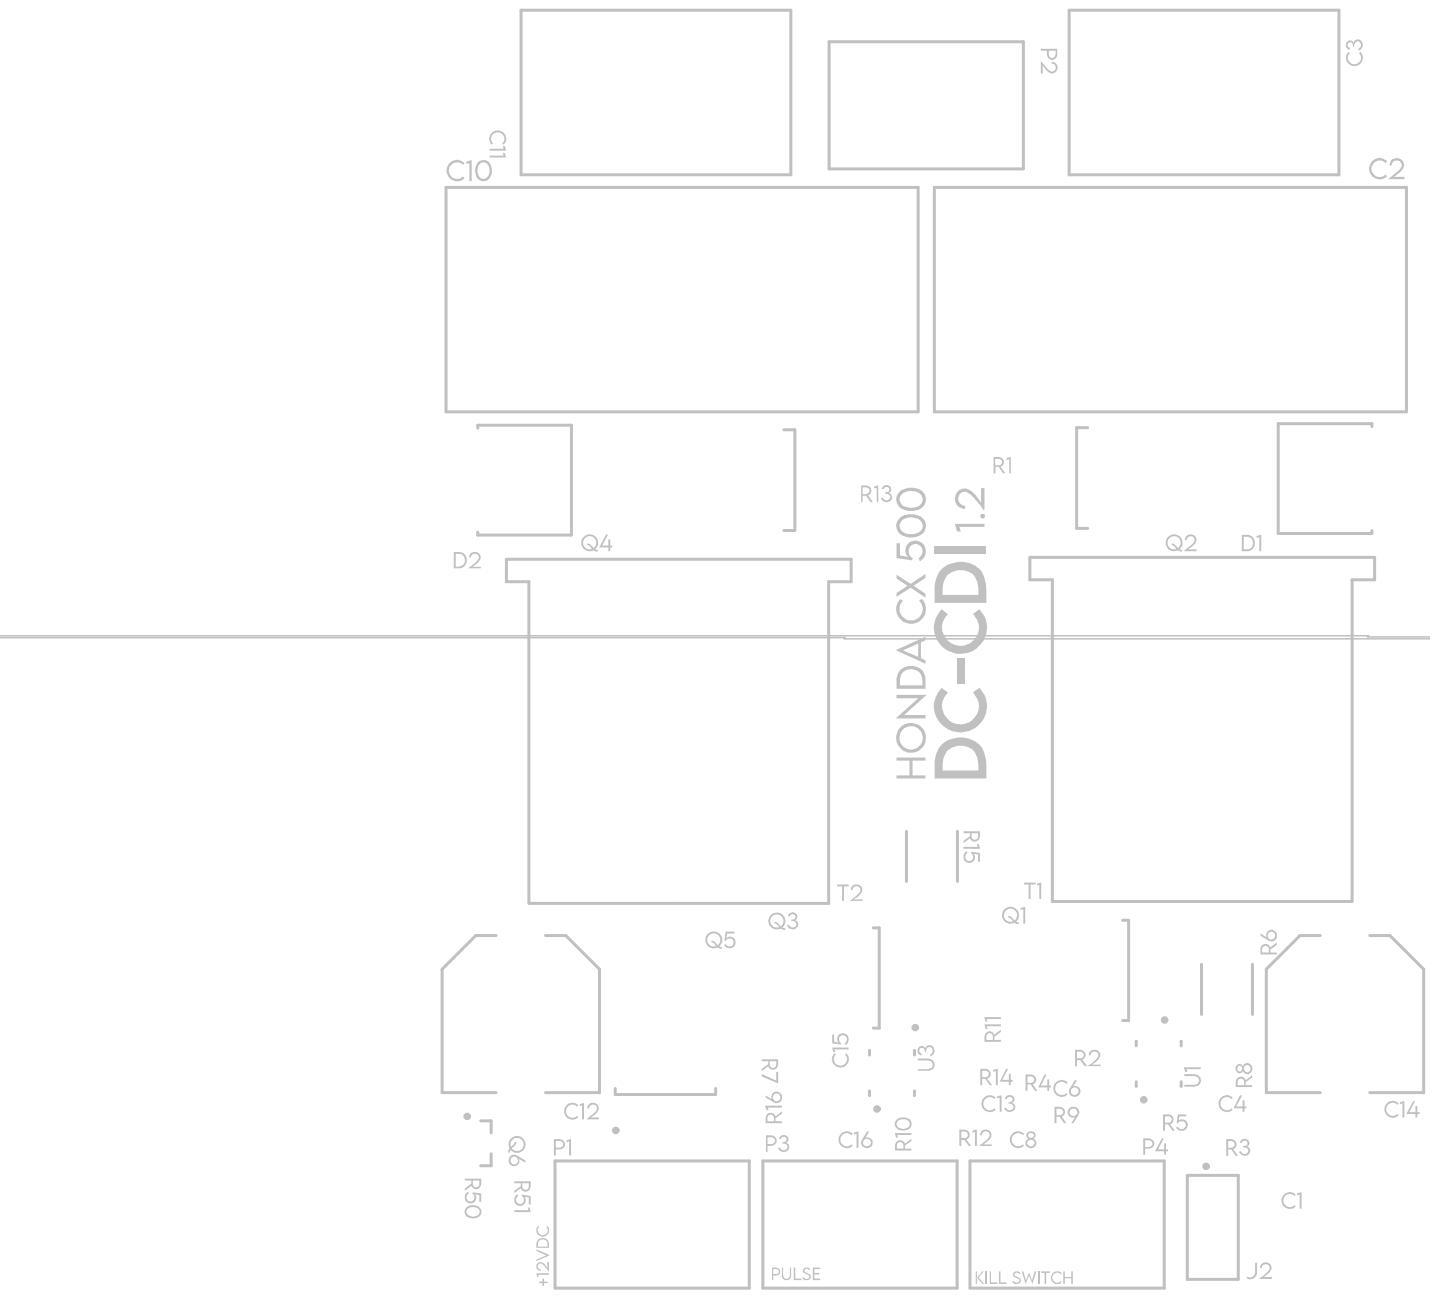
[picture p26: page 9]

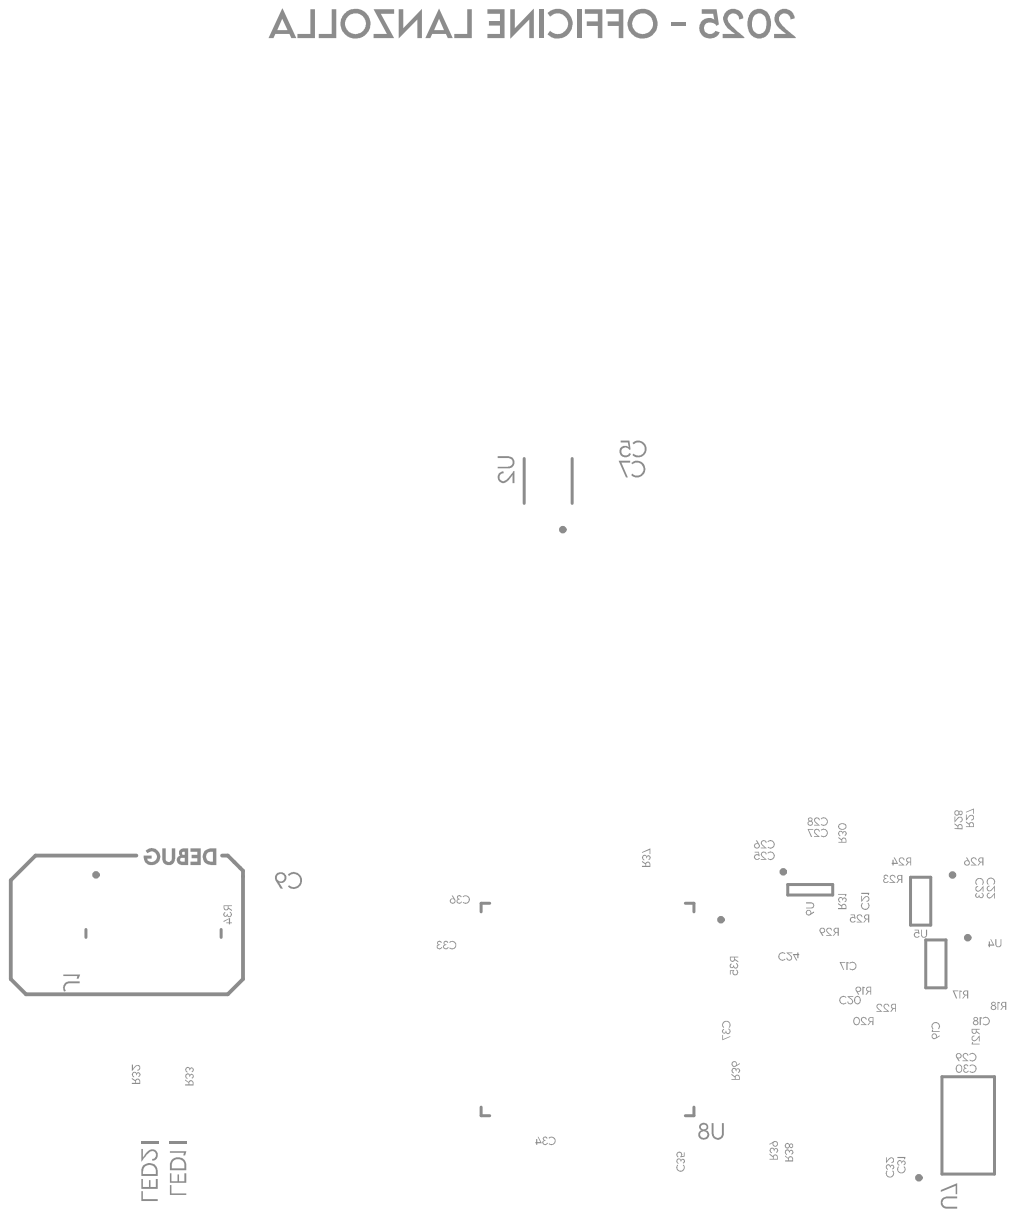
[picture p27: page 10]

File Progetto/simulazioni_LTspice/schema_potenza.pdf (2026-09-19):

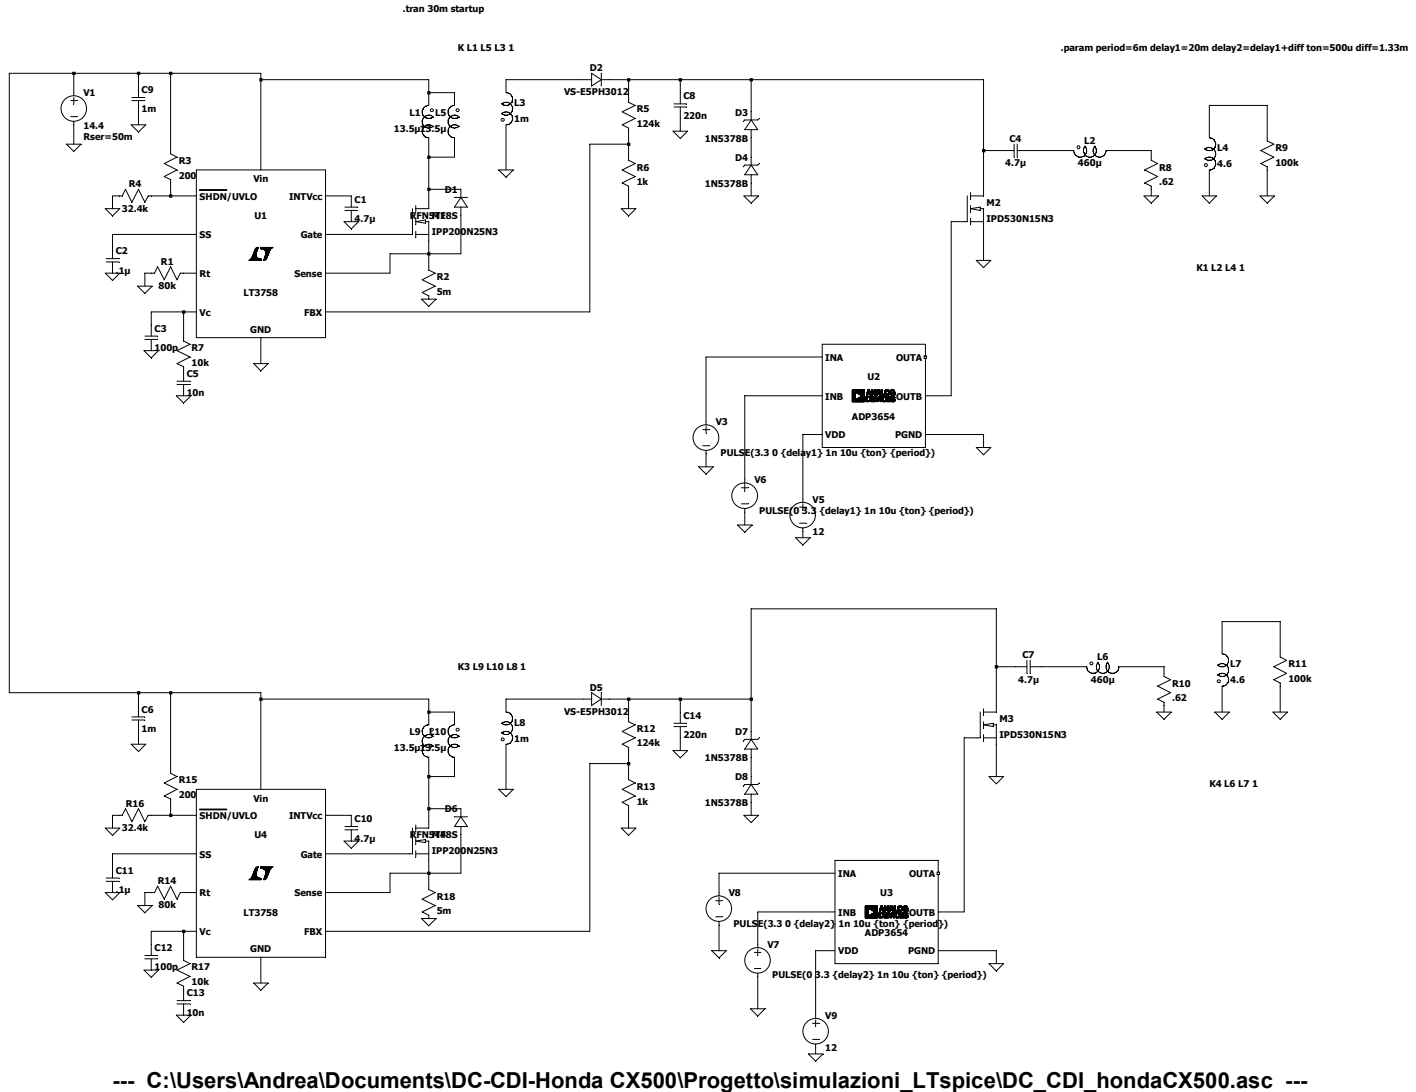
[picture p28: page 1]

.param period=6m delay1=20m delay2=delay1+diff ton=500u diff=1.33m

--- C:\Users\Andrea\Documents\DC-CDI-Honda CX500\Progetto\simulazioni_LTspice\DC_CDI_hondaCX500.asc ---

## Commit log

2026-09-19 Initial hardware design import
    [0805_R.SchLib, 1755749.SchLib, 1755752.SchLib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]
2026-09-19 Change image reference for Rev 1 assembly
    Updated image reference in README for Rev 1 assembly.
2026-09-20 rev2.2 altium edits
    [HV_power.SchDoc, dc_cdi_cx500.PcbDoc]
2026-09-21 Replace images for PCB revisions in README
    Updated images in README to reflect new PCB revisions.
2026-11-10 Add image for Rev 2.x PCB assembly
